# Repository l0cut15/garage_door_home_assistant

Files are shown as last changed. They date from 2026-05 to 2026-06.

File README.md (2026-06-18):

# Garage Door Controller — Home Assistant and HomeKit Integration

Smart garage door controller for the **Marantec Comfort 280** opener. Runs ESPHome firmware, integrates with Home Assistant, and is exposed to Apple HomeKit via Homebridge.

Two published hardware variants — pick the one that suits your install:

| Variant | Firmware | Board | Notes |
|---|---|---|---|
| ESP32-C3 Super Mini | `garage_door_esp32-c3.yaml` | ESP32-C3 Super Mini | Compact; esp-idf framework |
| ESP32U External Antenna | `garage_door_esp32.yaml` | ESP32U (ESP32dev) | External antenna for better range; Arduino framework |

Fully local — no cloud dependency. Self-powered from the opener's own 24V DC auxiliary rail.

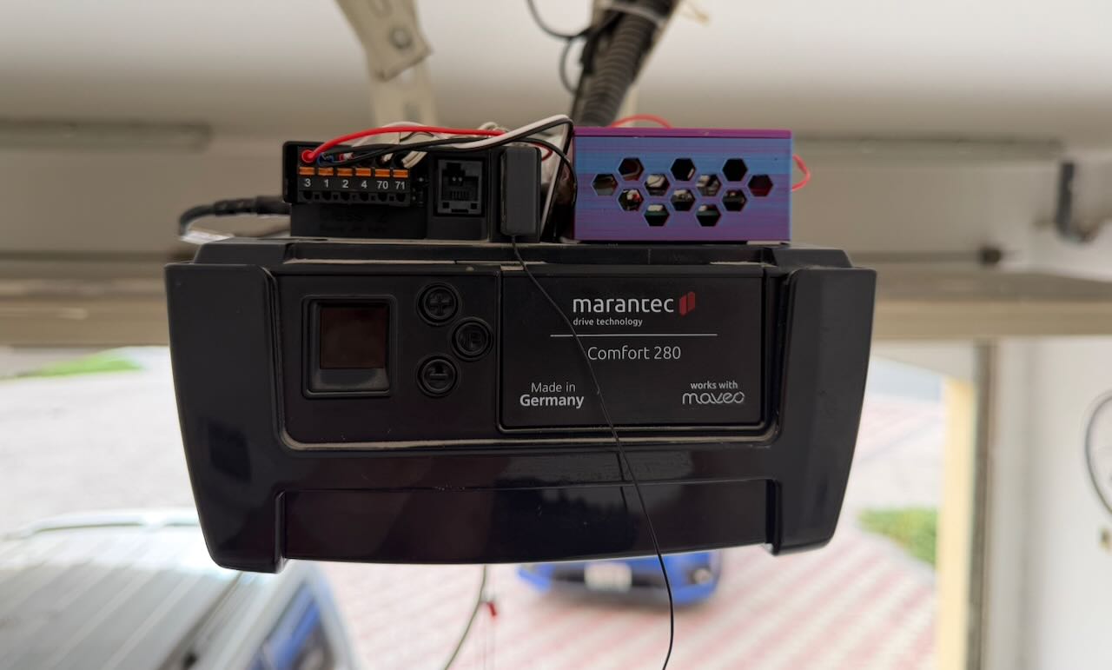
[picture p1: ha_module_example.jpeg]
Home Assistant


---

## Features

- Open / close / stop from Home Assistant dashboard or Apple Home
- Appears as a native garage door accessory in HomeKit
- Real-time door state via VL53L0X time-of-flight sensor (no door wiring required)
- Galvanically isolated trigger (G3VM-61A1 MOSFET SSR)
- Self-powered from Marantec 24V rail via buck converter

---

## Hardware

| Component | Part | ESP32-C3 variant | ESP32U variant |
|---|---|---|---|
| Microcontroller | — | ESP32-C3 Super Mini (`esp32-c3-devkitm-1`) | ESP32U (`esp32dev`) |
| Solid State Relay | OMRON G3VM-61A1 | SOP-4; galvanic isolation | SOP-4; galvanic isolation |
| Current limit resistor | 220Ω | SSR LED drive ~10mA | SSR LED drive ~10mA |
| Buck converter | Mini 5605V (preset 5V) | 24V → 5V | 24V → 5V |
| Distance sensor | CJVL53L0XV2 (VL53L0X breakout) | I2C, 3.3V, ceiling-mounted | I2C, 3.3V, ceiling-mounted |

---

## Architecture

### ESP32-C3 Super Mini

```
Apple Home / Siri
    ↕  HomeKit (Homebridge)
Home Assistant
    ↕  ESPHome Native API (encrypted, local WiFi)
ESP32-C3 Super Mini
    GPIO7  → 220Ω → G3VM-61A1 → Marantec XB03 terminals 1+2  (impulse trigger)
    GPIO1 (SDA) / GPIO3 (SCL) → I2C 10kHz → CJVL53L0XV2 (ceiling-mounted)
    5V  ← Mini 5605V buck converter ← Marantec XB03 terminal 3 (24V)
```

### ESP32U External Antenna

```
Apple Home / Siri
    ↕  HomeKit (Homebridge)
Home Assistant
    ↕  ESPHome Native API (encrypted, local WiFi)
ESP32U (esp32dev)
    GPIO17 → 220Ω → G3VM-61A1 → Marantec XB03 terminals 1+2  (impulse trigger)
    GPIO26 (SDA) / GPIO27 (SCL) → I2C 10kHz → CJVL53L0XV2 (ceiling-mounted)
    5V  ← Mini 5605V buck converter ← Marantec XB03 terminal 3 (24V)
```

---

## Wiring

See [`hardware.md`](hardware.md) for the bill of materials and full wiring diagrams.

### Marantec XB03 Terminal Block

```
[ 3 ][ 1 ][ 2 ][ 4 ][ 70 ][ 71 ]
```

| Terminal | Function | Connection |
|---|---|---|
| 1 | GND | G3VM pin 3 or 4; buck converter IN− |
| 2 | Pulse input | G3VM pin 3 or 4 |
| 3 | 24V DC output | Buck converter IN+ |
| 70/71 | Photocell safety | Do not touch |

---

## Firmware

### Prerequisites

- [ESPHome](https://esphome.io) installed
- `secrets.yaml` in project root (see `secrets.example.yaml`)

### secrets.yaml

```yaml
wifi_ssid: "your_ssid"
wifi_password: "your_password"
ap_fallback_password: "your_fallback_password"
esphome_api_key: "your_base64_api_key"
ota_password: "your_ota_password"
```

Generate the API key:
```bash
python3 -c "import secrets, base64; print(base64.b64encode(secrets.token_bytes(32)).decode())"
```

### Flash

```bash
# ESP32-C3 Super Mini
esphome run garage_door_esp32-c3.yaml

# ESP32U External Antenna
esphome run garage_door_esp32.yaml
```

Subsequent updates are OTA over WiFi.

---

## HomeKit via Homebridge

The [Homebridge addon](https://github.com/homebridge/homebridge-homeassistant) runs inside Home Assistant.

1. Install the **Homebridge** addon from the Home Assistant addon store
2. Start the addon and open the Homebridge UI from the HA sidebar
3. Open the **Home** app on iPhone and add an accessory
4. Scan the QR code displayed in the Homebridge UI

---

## Repository Structure

```
garage_door_esp32-c3.yaml  # ESP32-C3 Super Mini firmware
garage_door_esp32.yaml     # ESP32U external antenna firmware
hardware.md                # Bill of materials and wiring guide
secrets.example.yaml       # Secrets template
Board/                     # Fritzing layout files
3DPrint/                   # 3D print files (STL, source, mounts)
```

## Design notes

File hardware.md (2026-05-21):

# Hardware Reference — Garage Door Controller V2

**Board:** ESP32-C3 Super Mini  
**Power:** Mini 5605V buck converter (Marantec 24V → 5V)  
**Isolation:** OMRON G3VM-61A1 MOSFET SSR (DIP-4)  
**Sensor:** CJVL53L0XV2 (VL53L0X ToF breakout) — ceiling-mounted, I2C

---

## Bill of Materials

Prices are Aliexpress approximate retail in USD.

| # | Component | Detail | Qty | Unit (USD) | Line Total |
|---|---|---|---|---|---|
| 1 | ESP32-C3 Super Mini | `esp32-c3-devkitm-1` — MCU + WiFi | 1 | $2.50 | $2.50 |
| 2 | CJVL53L0XV2 | VL53L0X ToF distance sensor breakout | 1 | $2.50 | $2.50 |
| 3 | Mini 5605V | Adjustable buck converter, 24V→5V | 1 | $2 | $2 |
| 4 | G3VM-61A1 | Omron optocoupled SSR — galvanic isolation for Marantec trigger | 1 | $2 | $2 |
| 5 | Resistor, 220Ω | Current limiting, GPIO7 → SSR | 1 | <$0.10 | <$0.10 |
| 6 | Resistor, 47kΩ | I2C pull-ups — SDA and SCL to 3.3V | 2 | <$0.10 | <$0.10 |
| 7 | Perfboard 40×60mm | Solder-on stripboard, permanent mount | 1 | $1 | $1 |
| 8 | Pin headers | Male/female for module mounting on perfboard | 1 set | $0.50 | $0.50 |
| 9 | Hookup wire | Short runs on perfboard between components | — | $0.50 | $0.50 |
| 10 | Screw terminal block | 2-way, for Marantec XB03 connection | 1 | $0.30 | $0.30 |
| 11 | Ethernet patch cable | 1.4m, I2C extension to ceiling sensor | 1 | $2.50 | $2.50 |
| 12 | 10mm tube | Sensor bracket arm (aluminium or similar), ~150mm | 1 | $1 | $1 |
| 13 | PLA/PETG filament | Vertical sensor bracket (`3DPrint/Roof Bracket Vertical Mount.stl`), ~15g | — | $0.30 | $0.30 |
| | | | | **Total** | **~$15** |

**Notes:**
- The G3VM-61A1 is DIP-4 (through-hole) — solders directly onto perfboard
- The CJVL53L0XV2 does **not** include onboard pull-up resistors — the 47kΩ resistors are required. If rebuilding, 4.7kΩ is the better value for the 1.4m cable run
- The Marantec XB03 provides 24V @ 50mA max — the Mini 5605V is sized for that supply constraint

---

## Pin Assignments

| Signal | GPIO | Notes |
|---|---|---|
| SSR trigger | GPIO7 | Drives G3VM-61A1 via 220Ω resistor |
| I2C SDA | GPIO1 | VL53L0X data |
| I2C SCL | GPIO3 | VL53L0X clock |
| Power in | 5V pin | From Mini 5605V buck converter |
| Sensor power | 3.3V pin | VL53L0X VCC — must be 3.3V, not 5V |
| Ground | GND | Shared: ESP, buck converter, sensor |

---

## G3VM-61A1 Pin Reference (DIP-4)

```
        ┌───────┐
 Pin 1 ─┤ anode │
 Pin 2 ─┤cathode│  ← Input (LED) side
        │       │
 Pin 3 ─┤       │
 Pin 4 ─┤       │  ← Output (MOSFET) side
        └───────┘
```

| Pin | Function | Connection |
|---|---|---|
| 1 | Input anode (LED +) | 220Ω resistor → GPIO7 |
| 2 | Input cathode (LED −) | GND |
| 3 | Output | Marantec XB03 Terminal 1 (GND) |
| 4 | Output | Marantec XB03 Terminal 2 (Pulse) |

Pins 3 and 4 are the MOSFET drain/source — polarity does not matter on the output side.

---

## Wiring

### 1 — Buck converter

```
Marantec XB03 Terminal 3 (24V) ──── Mini 5605V IN+
Marantec XB03 Terminal 1 (GND) ──── Mini 5605V IN−

Mini 5605V OUT+ ──── ESP32-C3 5V pin
Mini 5605V OUT− ──── ESP32-C3 GND
```

> **Before connecting the ESP:** Measure OUT+ to GND with a multimeter — must read **5.0V ±0.2V**.

---

### 2 — SSR input drive

```
ESP32-C3 GPIO7 ──── 220Ω ──── G3VM Pin 1 (anode)
ESP32-C3 GND   ─────────────  G3VM Pin 2 (cathode)
```

The 220Ω resistor limits LED current to ~10mA: (3.3V − 1.2V) / 220Ω ≈ 9.5mA, within the G3VM's 5–50mA control range.

---

### 3 — SSR output → Marantec XB03

```
G3VM Pin 3 ──── Marantec XB03 Terminal 1 (GND)
G3VM Pin 4 ──── Marantec XB03 Terminal 2 (Pulse)
```

When GPIO7 goes HIGH, the MOSFET output closes, momentarily shorting Terminal 2 to Terminal 1 — identical to pressing the wall button. No voltage crosses from the ESP side to the Marantec side.

---

### 4 — VL53L0X ToF sensor

```
ESP32-C3 3.3V pin ──── VL53L0X VCC
ESP32-C3 GND      ──── VL53L0X GND
ESP32-C3 GPIO1    ──── VL53L0X SDA
ESP32-C3 GPIO3    ──── VL53L0X SCL

3.3V ──── 47kΩ ──── GPIO1 (SDA)   ← external pull-up
3.3V ──── 47kΩ ──── GPIO3 (SCL)   ← external pull-up
```

> **3.3V only:** Powering the module from 5V will put 5V logic on the I2C lines and damage the ESP32-C3. Use the 3.3V pin exclusively.

The sensor is ceiling-mounted via 1.4m of ethernet cable on a 3D-printed vertical bracket (`3DPrint/Roof Bracket Vertical Mount.stl`), pointing straight down at the top of the door panel.

**I2C pull-ups:** The CJVL53L0XV2 does **not** include onboard pull-up resistors. Two 47kΩ resistors on the breadboard (SDA and SCL to 3.3V) are the only pull-ups in the circuit. 47kΩ is weak for a 1.4m cable run — if rebuilding, use 4.7kΩ instead, which gives adequate rise time with less risk of marginal operation. The 47kΩ values work at 10kHz but leave little margin. **I2C must be run at 10kHz** — the 1.4m ethernet cable has high capacitance; 100kHz causes data corruption that produces phantom distance readings without generating I2C bus errors.

---

## Connection Diagram

```
                 ESP32-C3 Super Mini
                 ┌──────────────────┐
          3.3V ──┤                  ├── GPIO7 ── 220Ω ── G3VM Pin 1 (anode)
           GND ──┤                  ├── GND  ─────────── G3VM Pin 2 (cathode)
            5V ──┤                  ├── GPIO1 (SDA) ──┬─ VL53L0X SDA
                 │                  ├── GPIO3 (SCL) ──┼─ VL53L0X SCL
                 └──────────────────┘                 │
                       │       │                      │
                  5V pin     3.3V pin ── 47kΩ ─── GPIO1 (SDA)  ← pull-up
                       │       │     └─ 47kΩ ─── GPIO3 (SCL)  ← pull-up
              Mini 5605V    VL53L0X VCC
              OUT+

  G3VM Pin 3 ──── Marantec XB03 Terminal 1 (GND)
  G3VM Pin 4 ──── Marantec XB03 Terminal 2 (Pulse)

  Mini 5605V IN+ ──── Marantec XB03 Terminal 3 (24V)
  Mini 5605V IN− ──── Marantec XB03 Terminal 1 (GND)
```

---

## Marantec XB03 Terminal Block

```
[ 3 ][ 1 ][ 2 ][ 4 ][ 70 ][ 71 ]
```

| Terminal | Function | Connection |
|---|---|---|
| 1 | GND | G3VM Pin 3; buck IN− |
| 2 | Pulse input | G3VM Pin 4 |
| 3 | 24V DC output | Buck IN+ |
| 70/71 | Photocell safety | Do not touch |

---

## Bench Test Procedure

### Step 1 — Buck converter (before connecting ESP)

1. Connect Mini 5605V IN+/IN− to Marantec XB03 terminals 3 and 1.
2. Measure OUT+ to GND — must read **5.0V ±0.2V** before proceeding.

### Step 2 — Sensor detection

3. Flash firmware and connect to logs: `esphome logs garage_door_v2.yaml`
4. On boot, look for: `[I][i2c.idf:069]: Found i2c device at address 0x29`
5. If 0x29 is not listed, stop and check SDA/SCL wiring and VCC before proceeding.

### Step 3 — SSR trigger

6. In Home Assistant → Developer Tools → Actions, call `cover.open_cover` on the Garage Door entity.
7. Probe G3VM pins 3 and 4 with a multimeter set to continuity — should close (beep) for ~300ms then release.

### Step 4 — End-to-end

8. Connect G3VM output to Marantec XB03 terminals 1 and 2.
9. Trigger open and close from HA and confirm the cover entity transitions correctly through Open → Closing → Closed → Opening → Open.

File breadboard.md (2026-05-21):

# Wiring Guide — Garage Door Controller V2

**Board:** ESP32-C3 Super Mini  
**Power:** Mini 5605V buck converter (Marantec 24V → 5V)  
**Isolation:** OMRON G3VM-61A1 MOSFET SSR (SOP-4)  
**Sensor:** CJVL53L0XV2 (VL53L0X ToF breakout) — ceiling-mounted, I2C

---

## Pin Assignments

| Signal | GPIO | Notes |
|---|---|---|
| SSR trigger | GPIO7 | Drives G3VM-61A1 via 220Ω resistor |
| I2C SDA | GPIO1 | VL53L0X data |
| I2C SCL | GPIO3 | VL53L0X clock |
| Power in | 5V pin | From Mini 5605V buck converter |
| Sensor power | 3.3V pin | VL53L0X VCC — must be 3.3V, not 5V |
| Ground | GND | Shared: ESP, buck converter, sensor |

---

## Components

| Item | Qty | Notes |
|---|---|---|
| ESP32-C3 Super Mini | 1 | `esp32-c3-devkitm-1`, esp-idf framework |
| OMRON G3VM-61A1 | 1 | SOP-4 package |
| Resistor, 220Ω | 1 | Sets SSR LED drive current to ~10mA |
| Resistor, 47kΩ | 2 | I2C pull-ups — SDA and SCL to 3.3V (see note below) |
| CJVL53L0XV2 breakout | 1 | VL53L0X ToF sensor, I2C address 0x29 |
| Mini 5605V buck module | 1 | Pre-set to 5V; powers ESP from Marantec 24V rail |

---

## G3VM-61A1 Pin Reference (SOP-4)

```
        ┌───────┐
 Pin 1 ─┤ anode │
 Pin 2 ─┤cathode│  ← Input (LED) side
        │       │
 Pin 3 ─┤       │
 Pin 4 ─┤       │  ← Output (MOSFET) side
        └───────┘
```

| Pin | Function | Connection |
|---|---|---|
| 1 | Input anode (LED +) | 220Ω resistor → GPIO7 |
| 2 | Input cathode (LED −) | GND |
| 3 | Output | Marantec XB03 Terminal 1 (GND) |
| 4 | Output | Marantec XB03 Terminal 2 (Pulse) |

Pins 3 and 4 are the MOSFET drain/source — polarity does not matter on the output side.

---

## Wiring

### 1 — Buck converter

```
Marantec XB03 Terminal 3 (24V) ──── Mini 5605V IN+
Marantec XB03 Terminal 1 (GND) ──── Mini 5605V IN−

Mini 5605V OUT+ ──── ESP32-C3 5V pin
Mini 5605V OUT− ──── ESP32-C3 GND
```

> **Before connecting the ESP:** Measure OUT+ to GND with a multimeter — must read **5.0V ±0.2V**.

---

### 2 — SSR input drive

```
ESP32-C3 GPIO7 ──── 220Ω ──── G3VM Pin 1 (anode)
ESP32-C3 GND   ─────────────  G3VM Pin 2 (cathode)
```

The 220Ω resistor limits LED current to ~10mA: (3.3V − 1.2V) / 220Ω ≈ 9.5mA, within the G3VM's 5–50mA control range.

---

### 3 — SSR output → Marantec XB03

```
G3VM Pin 3 ──── Marantec XB03 Terminal 1 (GND)
G3VM Pin 4 ──── Marantec XB03 Terminal 2 (Pulse)
```

When GPIO7 goes HIGH, the MOSFET output closes, momentarily shorting Terminal 2 to Terminal 1 — identical to pressing the wall button. No voltage crosses from the ESP side to the Marantec side.

---

### 4 — VL53L0X ToF sensor

```
ESP32-C3 3.3V pin ──── VL53L0X VCC
ESP32-C3 GND      ──── VL53L0X GND
ESP32-C3 GPIO1    ──── VL53L0X SDA
ESP32-C3 GPIO3    ──── VL53L0X SCL

3.3V ──── 47kΩ ──── GPIO1 (SDA)   ← external pull-up
3.3V ──── 47kΩ ──── GPIO3 (SCL)   ← external pull-up
```

> **3.3V only:** Powering the module from 5V will put 5V logic on the I2C lines and damage the ESP32-C3. Use the 3.3V pin exclusively.

The sensor is ceiling-mounted via 1.4m of ethernet cable on a 3D-printed vertical bracket (`3DPrint/Roof Bracket Vertical Mount.stl`), pointing straight down at the top of the door panel.

**I2C pull-ups:** The CJVL53L0XV2 does **not** include onboard pull-up resistors. Two 47kΩ resistors on the breadboard (SDA and SCL to 3.3V) are the only pull-ups in the circuit. 47kΩ is weak for a 1.4m cable run — if rebuilding, use 4.7kΩ instead, which gives adequate rise time with less risk of marginal operation. The 47kΩ values work at 10kHz but leave little margin. **I2C must be run at 10kHz** — the 1.4m ethernet cable has high capacitance; 100kHz causes data corruption that produces phantom distance readings without generating I2C bus errors.

---

## Connection Diagram

```
                 ESP32-C3 Super Mini
                 ┌──────────────────┐
          3.3V ──┤                  ├── GPIO7 ── 220Ω ── G3VM Pin 1 (anode)
           GND ──┤                  ├── GND  ─────────── G3VM Pin 2 (cathode)
            5V ──┤                  ├── GPIO1 (SDA) ──┬─ VL53L0X SDA
                 │                  ├── GPIO3 (SCL) ──┼─ VL53L0X SCL
                 └──────────────────┘                 │
                       │       │                      │
                  5V pin     3.3V pin ── 47kΩ ─── GPIO1 (SDA)  ← pull-up
                       │       │     └─ 47kΩ ─── GPIO3 (SCL)  ← pull-up
              Mini 5605V    VL53L0X VCC
              OUT+

  G3VM Pin 3 ──── Marantec XB03 Terminal 1 (GND)
  G3VM Pin 4 ──── Marantec XB03 Terminal 2 (Pulse)

  Mini 5605V IN+ ──── Marantec XB03 Terminal 3 (24V)
  Mini 5605V IN− ──── Marantec XB03 Terminal 1 (GND)
```

---

## Marantec XB03 Terminal Block

```
[ 3 ][ 1 ][ 2 ][ 4 ][ 70 ][ 71 ]
```

| Terminal | Function | Connection |
|---|---|---|
| 1 | GND | G3VM Pin 3; buck IN− |
| 2 | Pulse input | G3VM Pin 4 |
| 3 | 24V DC output | Buck IN+ |
| 70/71 | Photocell safety | Do not touch |

---

## Bench Test Procedure

### Step 1 — Buck converter (before connecting ESP)

1. Connect Mini 5605V IN+/IN− to Marantec XB03 terminals 3 and 1.
2. Measure OUT+ to GND — must read **5.0V ±0.2V** before proceeding.

### Step 2 — Sensor detection

3. Flash firmware and connect to logs: `esphome logs garage_door_v2.yaml`
4. On boot, look for: `[I][i2c.idf:069]: Found i2c device at address 0x29`
5. If 0x29 is not listed, stop and check SDA/SCL wiring and VCC before proceeding.

### Step 3 — SSR trigger

6. In Home Assistant → Developer Tools → Actions, call `cover.open_cover` on the Garage Door entity.
7. Probe G3VM pins 3 and 4 with a multimeter set to continuity — should close (beep) for ~300ms then release.

### Step 4 — End-to-end

8. Connect G3VM output to Marantec XB03 terminals 1 and 2.
9. Trigger open and close from HA and confirm the cover entity transitions correctly through Open → Closing → Closed → Opening → Open.

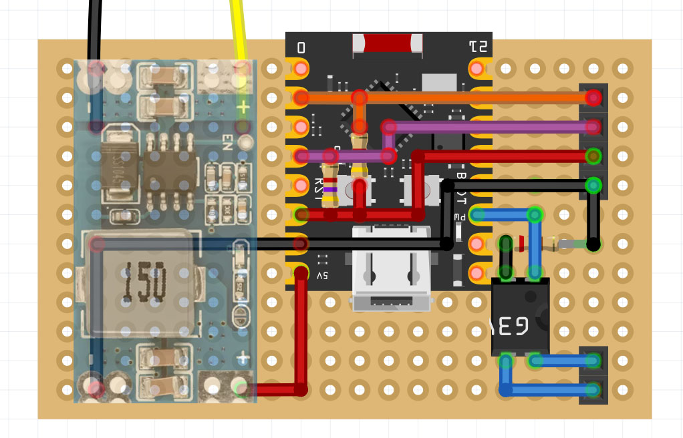
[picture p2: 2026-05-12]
Board/ESP32C3 V2 design.jpg

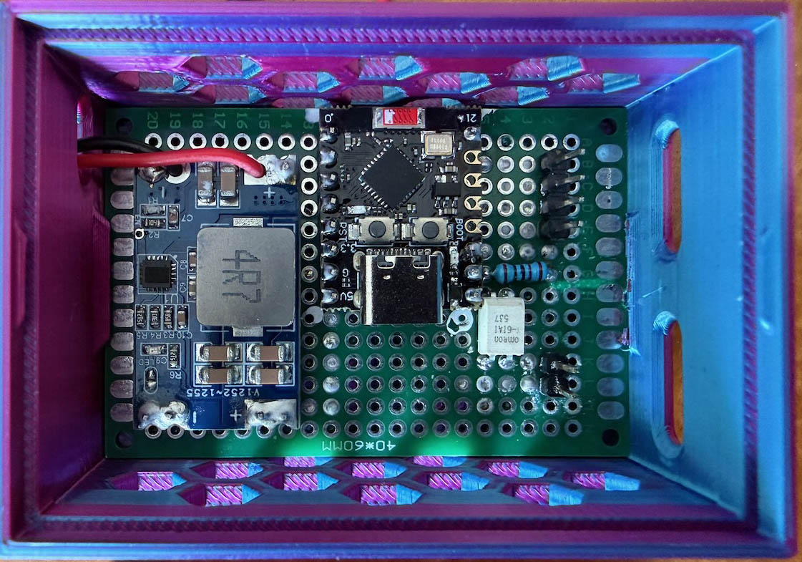
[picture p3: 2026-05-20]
c3-board.jpeg

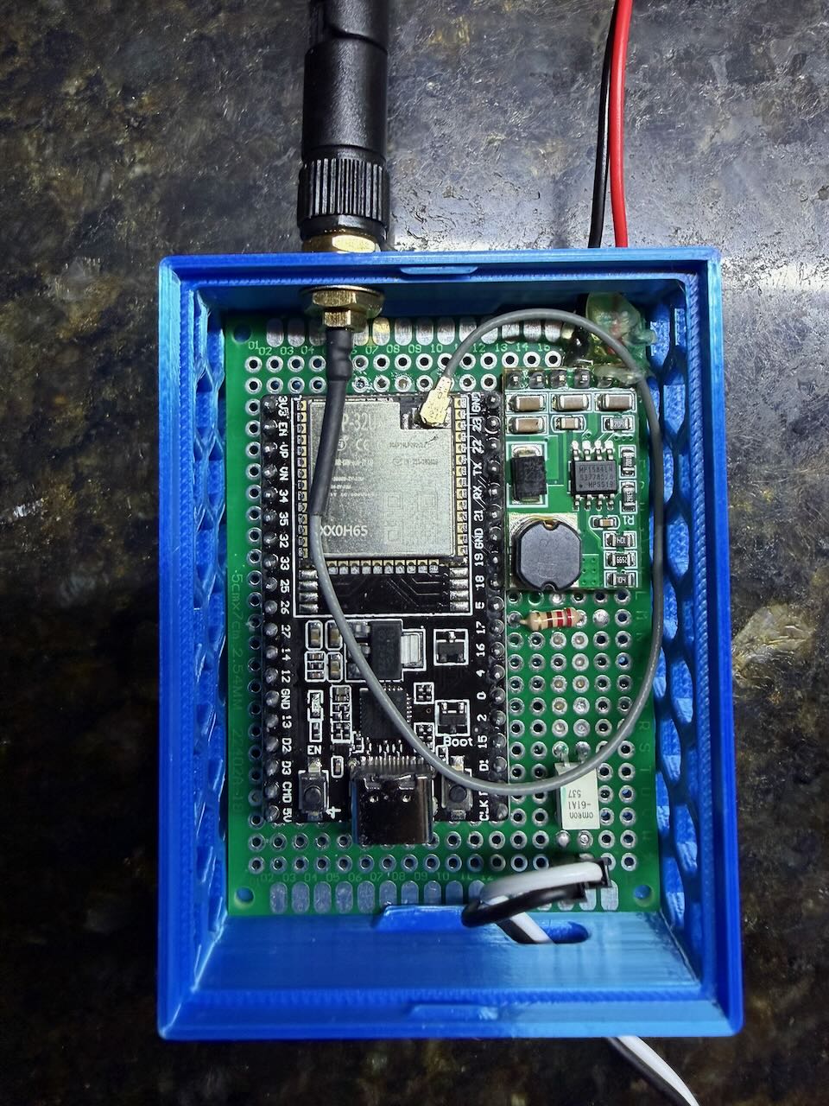
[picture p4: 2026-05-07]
sample-board.jpeg

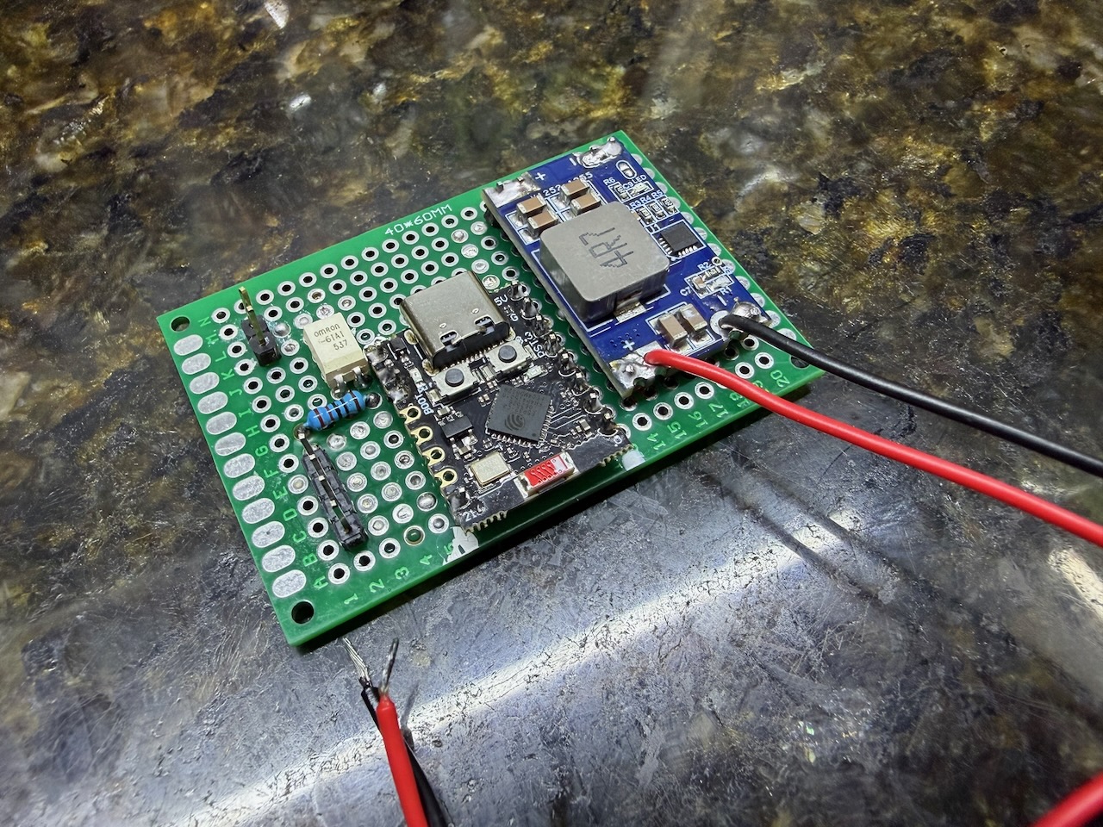
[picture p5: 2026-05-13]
sample-board-v2.jpeg

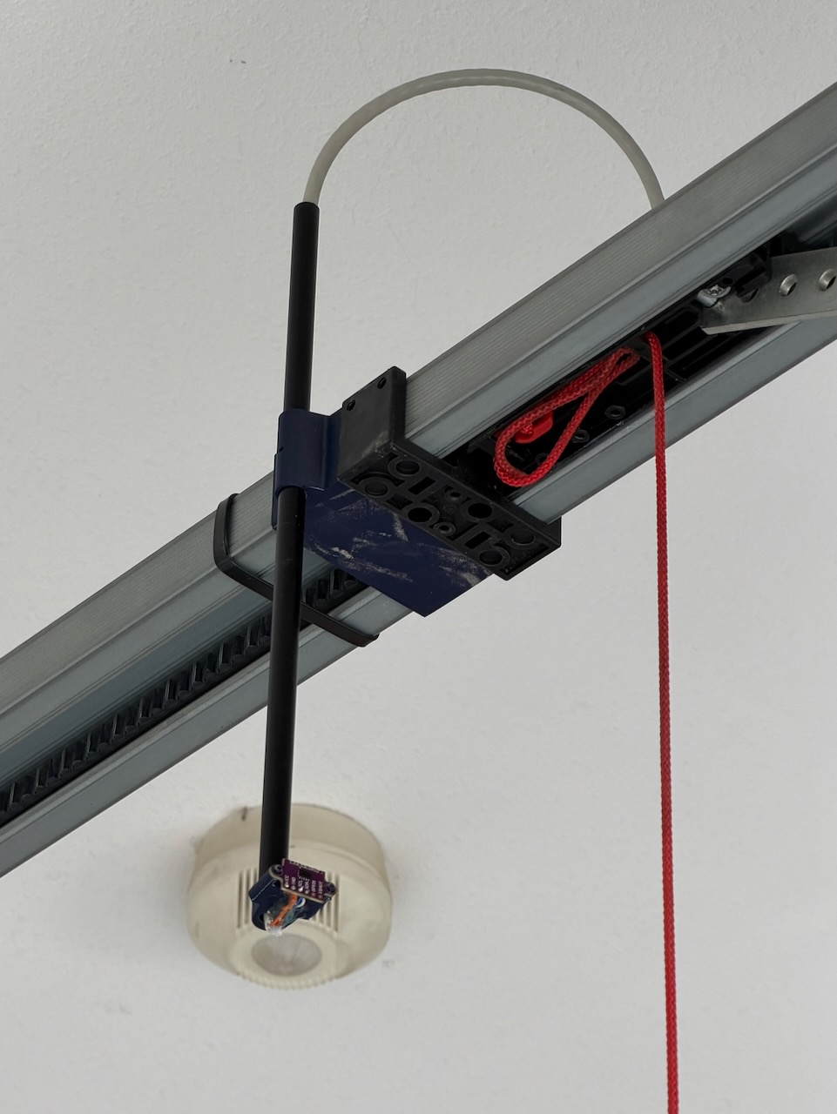
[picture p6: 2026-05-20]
3DPrint/sensor mount.jpeg

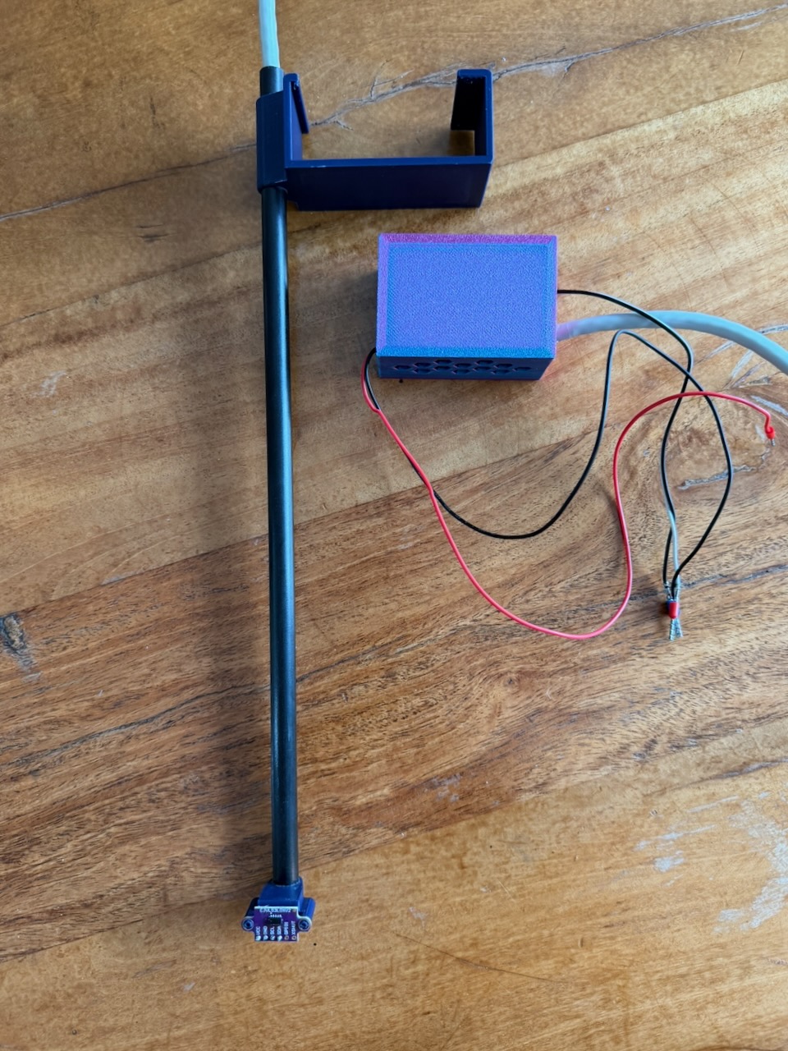
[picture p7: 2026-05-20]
3DPrint/c3-kit.jpeg

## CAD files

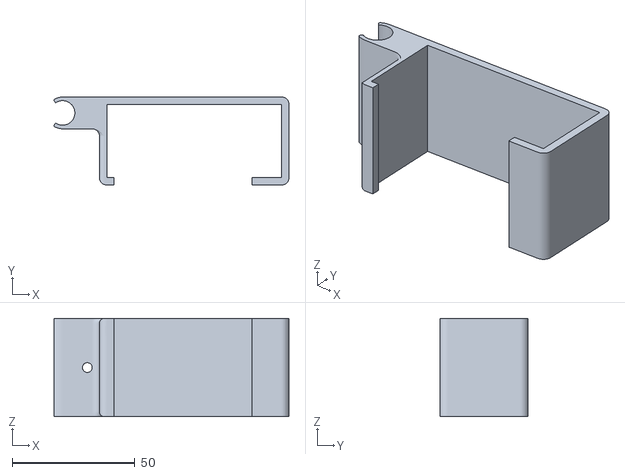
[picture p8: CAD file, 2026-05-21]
3DPrint/Roof Bracket Vertical Mount.stl
95.8 x 35.9 x 40.0

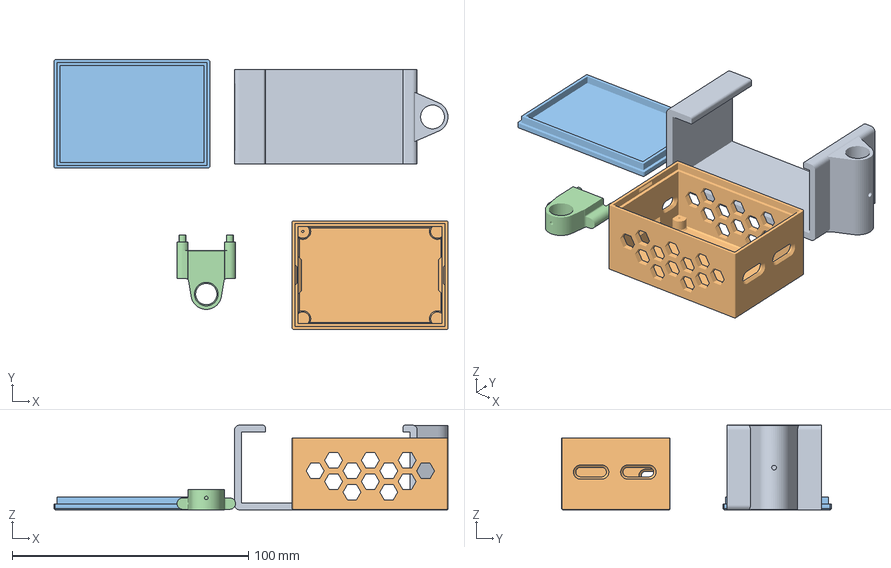
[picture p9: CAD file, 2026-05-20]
3DPrint/Garage Door Opener.3mf
166.9 x 114.3 x 35.9 mm
Roof Bracket.stl
Garage Door Opener C3 - Base.stl
Garage Door Opener C3 - Lid.stl
Distance Sensor.stl

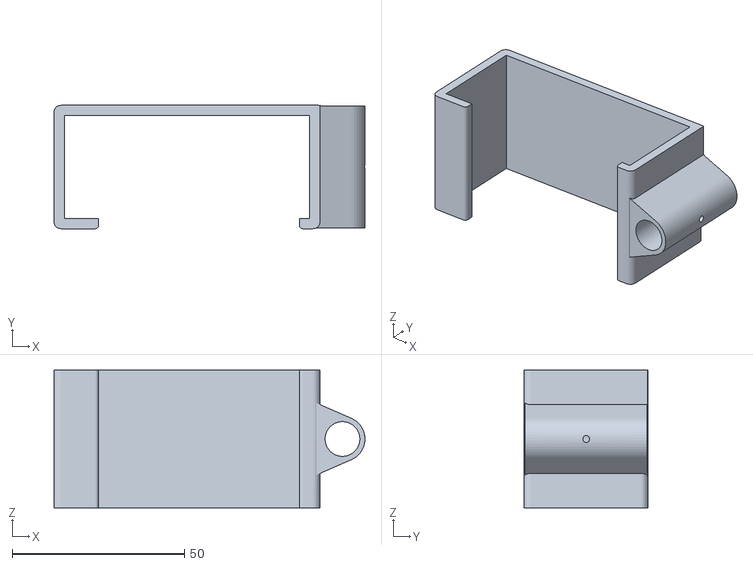
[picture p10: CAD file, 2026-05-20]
3DPrint/Roof Bracket.stl
90.4 x 35.9 x 40.0

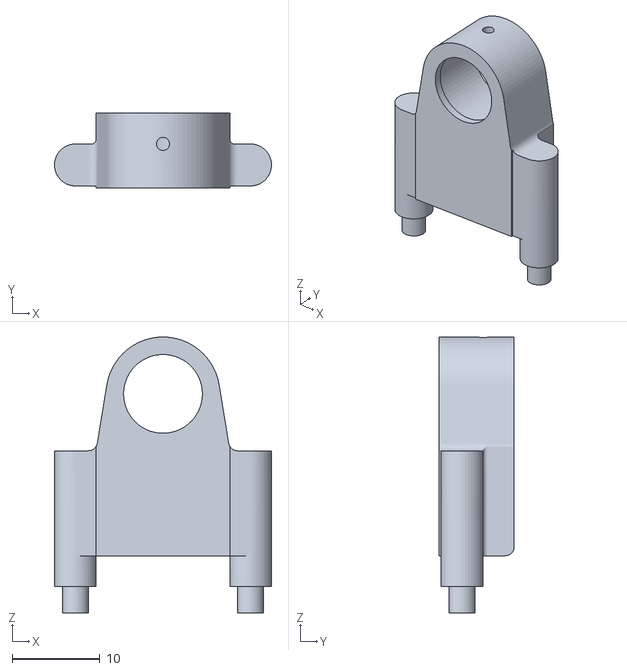
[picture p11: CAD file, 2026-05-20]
3DPrint/Distance Sensor.stl
24.8 x 8.60 x 31.5

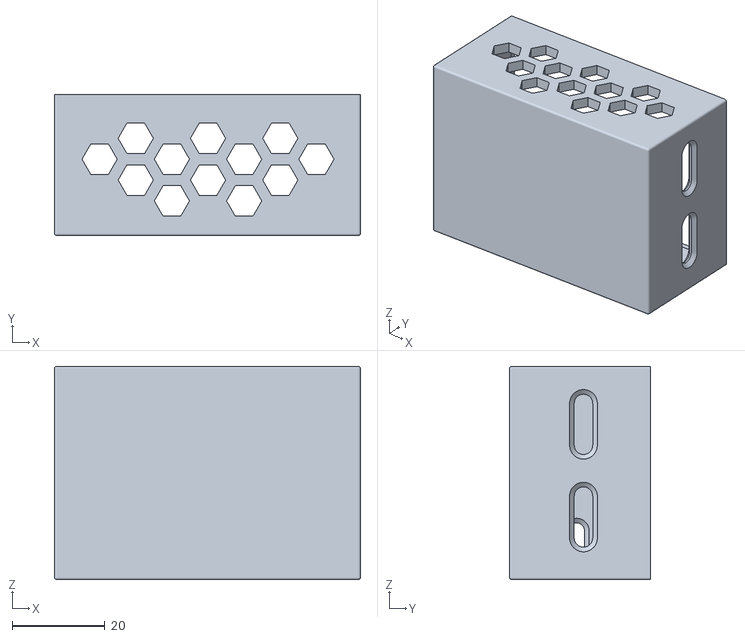
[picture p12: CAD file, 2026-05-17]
3DPrint/Garage Door Opener C3 - Base.stl
66.0 x 30.5 x 46.0

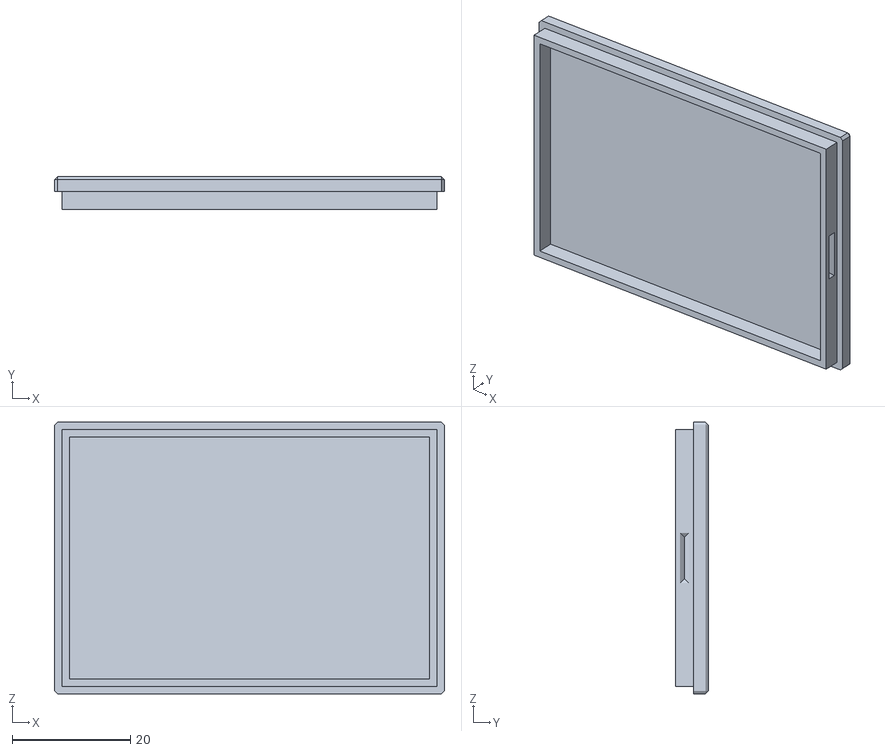
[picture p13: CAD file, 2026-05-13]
3DPrint/Garage Door Opener C3 - Lid.stl
66.0 x 5.50 x 46.0

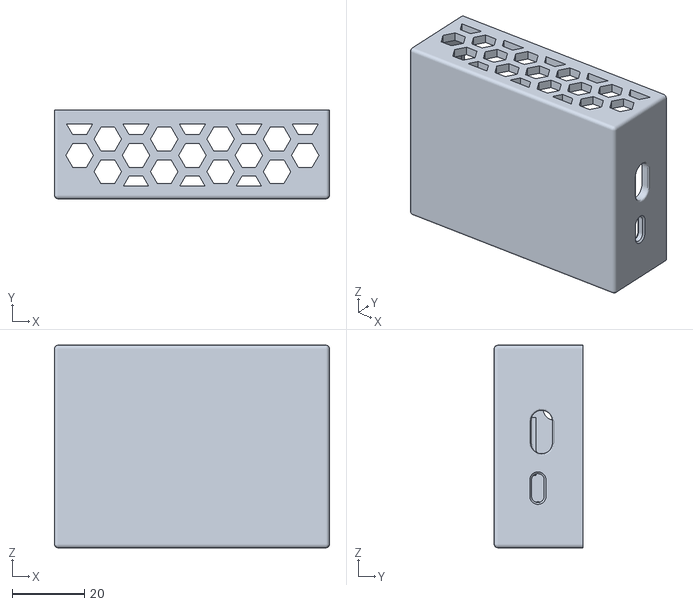
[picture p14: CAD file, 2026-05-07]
3DPrint/Garage Door Opener - base.stl
76.0 x 24.5 x 56.0

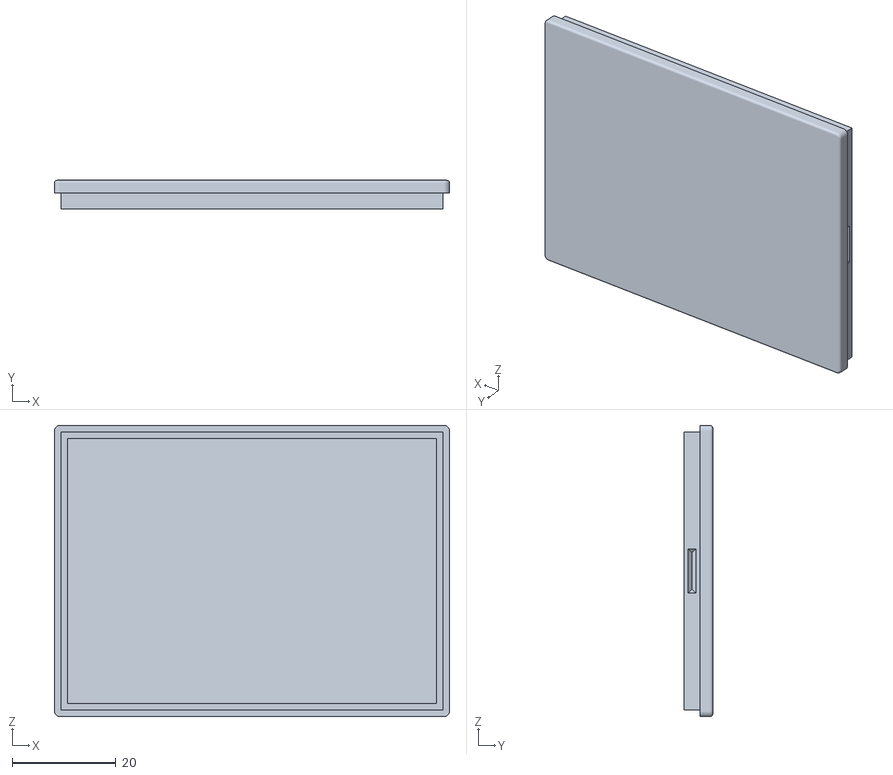
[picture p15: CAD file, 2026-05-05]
3DPrint/Garage Door Opener - Lid.stl
76.0 x 5.50 x 56.0

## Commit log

2026-05-04 Initial commit: ESP32-C3 garage door controller for Marantec Comfort 280
    ESPHome YAML firmware, design doc, breadboard notes, and Marantec manual.
    secrets.yaml excluded — copy secrets.example.yaml to get started.
2026-05-05 Added Dev board based on ESP32U for testing.
    [Garage Layout ESP32C3 24x10.fzz, Garage Layout ESP32U Breadboard.fzz, Garage Loyout 24x10.fzz]
2026-05-05 Bench prototype complete: protoboard build, GPIO17, 300ms pulse
    - SSR trigger pin updated to GPIO17 (soldered protoboard build)
    - Pulse duration restored to 300ms (from 3s test value)
    - Cover entity updated to optimistic + assumed_state for stateless open/close
    - Bluetooth proxy enabled on dev board
    - Breadboard Fritzing files replaced with protoboard layouts
    - Buck converter updated to MP1584EN (preset 5V, no trimmer)
    - All docs updated to reflect ESP32U dev board replacing D1 Mini prototype
    [Garage Layout ESP32U Protoboard 2.fzz, Garage Layout ESP32U Protoboard 24x18.fzz]
2026-05-05 v1.0: promote ESP32U protoboard build to production
    - Rename garage_door_dev.yaml → garage_door.yaml (v1 production firmware)
    - Remove superseded ESP8266/D1 Mini config
    - Update device name and friendly name (remove Dev branding)
    - Add README.md with hardware, wiring, firmware, and HomeKit setup
    - Add Case/ STL files (base + lid) for 3D printed enclosure
    - Clean up stale Fritzing files; retain current board layouts
    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
    [Garage Door Opener - Lid.stl, Garage Door Opener - base.stl, Garage Layout ESP32U Protoboard 2.fzz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]
2026-05-05 Add photo and README polish; remove capacitor from all docs
    - Add board pinout photo inline in README between Features and Hardware
    - Remove 470µF output capacitor from README, breadboard.md, and design doc
    - Simplify buck test procedure accordingly
2026-05-05 Fix Homebridge setup docs; add Fritzing board image
    - Replace incorrect token-based Homebridge config with correct QR code
    pairing flow — addon runs inside HA, no token required
    - Add Fritzing board layout image to Wiring section
2026-05-07 Updated Case
    [Garage Door Opener - base.stl]
2026-05-10 Fix XB03 terminal assignments; add V2 firmware and docs
    Terminal 1=GND, 2=Pulse, 3=24V — all wiring diagrams and docs were
    previously inverted. Also adds garage_door_v2.yaml (Lolin C3 Mini +
    VL53L0X ToF sensor) and expands CLAUDE.md with V2 architecture,
    calibration steps, and stop-button caveat.
2026-05-10 Fix remaining XB03 terminal errors in README, breadboard, YAML comments
    README.md, breadboard.md, garage_door.yaml, garage_door_v2.yaml, and
    garage_door_automation.md all still referenced the wrong terminals
    (1+3 for impulse, 2 for 24V). Corrected throughout: T1=GND, T2=Pulse,
    T3=24V DC.
2026-05-10 Fix board layout image in README wiring section
2026-05-12 Update V2 to ESP32-C3 Super Mini; add WiFi config and design image
    Switch board to esp32-c3-devkitm-1 with esp-idf framework, update GPIO
    pins (GPIO7 SSR, GPIO1/3 I2C), add required C3 WiFi settings (WPA3
    disabled, power_save_mode none, output_power 8.5, fast_connect), and
    add V2 design photo.
2026-05-13 Build V2 Board
    [Garage Door Opener C3 - Base.stl, Garage Door Opener C3 - Export.stl, Garage Layout ESP32C3 size with I2C Pins 01 03 and 07.fzz]
2026-05-17 Untrack Reference files and ignore Reference directory; add V2 board and case files
    [Garage Door Opener C3 Fusion.f3d, Garage Door Opener C3.3mf, Garage Door Opener C3.stl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]
2026-05-19 V2: implement sustained-NaN open detection; calibrate and document
    - garage_door_v2.yaml: implement Option B (sustained NaN → OPEN)
    - globals: had_valid_reading, nan_streak track NaN streak since boot
    - sensor on_value increments streak on NaN, resets on valid reading
    - cover lambda: CLOSED ≤ 0.72m; OPEN after 6× NaN (3s); indeterminate otherwise
    - closed_distance_m calibrated to 0.72m (measured 0.67m + 5cm margin)
    - open_distance_m set to 1.10m (above range; OPEN via NaN only)
    - horizontal ceiling mount confirmed; vertical rejected (same info, worse cabling)
    - CLAUDE.md: document real install data, mounting decision, Option B rationale
    - README.md: update to reflect V1/V2 s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
2026-05-20 V2: fix inverted open/closed logic; add EMA filter and delta throttle
    Sensor detects door panel from ceiling — valid reading means OPEN, NaN
    means CLOSED. Previous firmware had this backwards. Also adds EMA
    smoothing with isolated-NaN suppression and 2cm delta throttle to reduce
    spurious HA state updates while door is stationary.
2026-05-20 V2: recalibrate sensor position; fix cover timing; logger WARN; confirm stop
    Sensor repositioned — open distance recalibrated to 0.75m (measured
    ~0.704m + 5cm margin). Added update_interval: 500ms to cover template
    to fix 15s state-declaration delay. Logger set to WARN. Confirmed stop
    behaviour (Marantec reverses after stop — do not use stop + resume).
    HomeKit integration confirmed working end-to-end.
    [Distance Sensor.stl, Garage Door Opener - Lid.stl, Garage Door Opener - base.stl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]
2026-05-20 Fix: suppress repeated NaN publications after door closes
    Only publish NaN on the 2nd consecutive reading (transition signal).
    All subsequent NaN are suppressed — nan_streak still increments
    internally so CLOSED detection is unaffected.
2026-05-20 Update docs: V2 is current shipped version, V1 is retired prototype
    Remove stale had_valid_reading reference, update calibrated threshold to
    0.75m (repositioned sensor), check off all completed roadmap items.
2026-05-20 Replace Case/ with 3DPrint/; update README reference
    [Garage Door Opener - Lid.stl, Garage Door Opener - base.stl, Garage Door Opener C3 - Base.stl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]
2026-05-20 Track ha_module_example-old.jpeg
2026-05-20 Rewrite breadboard.md for V2: ESP32-C3, VL53L0X, remove V1 content
2026-05-20 Reduced sensor logging
2026-05-20 Add sensor kit lid STL; replace old C3 export files
    [Garage Door Opener C3 - Lid.stl, Garage Door Opener C3 Fusion.f3d, Garage Door Opener C3.3mf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]
2026-05-21 Rework V2 sensor mount to vertical bracket; rewrite state logic for new geometry
    Sensor repositioned from horizontal ceiling mount to a 3D-printed vertical bracket
    pointing straight down at the door panel. The previous horizontal mount caused the
    opener rail and drive mechanism to appear in the sensor field of view when the door
    was closed, producing constant phantom distance readings.
    Firmware changes:
    - open/closed detection now uses dual-streak counters (open_streak, closed_streak)
    replacing the old nan_streak-only approach
    - closed_streak counts both NaN and valid readings ≥1.0m, so a parked car
    correctly contributes to CLOSED rather than resetting detection
    - Dead zone 0.30m–1.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
    [Roof Bracket Vertical Mount.stl]
2026-05-21 Add 47kΩ I2C pull-up resistors to breadboard wiring doc and components list
2026-05-21 Correct I2C pull-up note: CJVL53L0XV2 has no onboard pull-ups
    The 47kΩ breadboard resistors are the only pull-ups in the circuit, not
    supplementary to onboard ones. Note that 4.7kΩ would be preferable for
    the 1.4m cable run.
2026-05-21 Rename breadboard.md → hardware.md; add bill of materials
    Combines wiring guide and BOM into a single hardware reference document.
    Updates README references accordingly.
2026-05-21 Switch BOM pricing to USD (Aliexpress)
2026-06-17 Add garage_door_ext.yaml for ESP32U with external antenna
    ESP32U (esp32dev) variant of V2 firmware: GPIO26/27 for I2C,
    GPIO18 for SSR trigger, arduino framework. No output_power cap —
    external antenna provides sufficient gain. Same streak-based door
    state logic and calibration values as V2.
2026-06-18 garage_door_ext: add GPIO25 I2C pull-up reference pin
    GPIO25 drives the 4.7kΩ pull-up resistors on SDA/SCL rather than
    tying them directly to 3.3V. ALWAYS_ON restore_mode ensures the pin
    is HIGH before the I2C bus initialises (GPIO setup priority 300 >
    I2C bus priority 250).
2026-06-18 Publish two firmware variants; rename and update docs
    - garage_door_esp32-c3.yaml: ESP32-C3 Super Mini (renamed from garage_door_v2.yaml)
    - garage_door_esp32.yaml: ESP32U external antenna (renamed from garage_door_ext.yaml)
    - Calibrated open_distance_m to 0.25m (measured ~0.175m + 7.5cm margin)
    - External pull-ups removed; onboard breakout pull-ups sufficient
    - Remove retired garage_door_v1_prototype.yaml
    - Update README and CLAUDE.md to reflect both published variants
    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
    [Garage v2 Layout ESP32U Protoboard 24x18.fzz, Garage v2 Layout ESP32U with I2C side socket Protoboard 24x18.fzz]
2026-09-18 Fix ESP32-C3 WiFi connection failure
    Remove CONFIG_ESP_WIFI_ENABLE_WPA3_SAE: "n" sdkconfig override, which
    was causing the device to fail to associate with the router. Also
    drop fast_connect and reboot_timeout (not implicated, but removed
    to match the confirmed-working bench config) and lower output_power
    to 8.5dB.
    Bench-tested only; not yet re-verified at the garage-mounted,
    edge-of-range install location. See CLAUDE.md for details.
